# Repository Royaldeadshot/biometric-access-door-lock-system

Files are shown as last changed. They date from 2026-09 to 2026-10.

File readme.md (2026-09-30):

# ESP32 Based Biometric Access Door Lock (Tailored for GYM)

## Motivation
I used to go my GYM and used to see this biometric access door lock, and one day it struck me, I can make one too, with some extra features. So here i'm building this.

## Features
1. **Fingerprint** Based Recognition.
2. **Exit** by Pressing a Button inside.
3. **Cool LED ring** around the Fingerprint sensor for Visual Feedback, which also shows cool animations while idle.
4. **Buzzer** for Audible Feedback.
5. **Real Time member** list fetching from Website's Database. (No extra hardware like a laptop required for its working, just a wifi connection and it works like a charm.)
6. **Easy Integration** with any custom website.
7. A Fail Secure Solenoid Door Lock, it keeps locked when electricity is gone.

## Parts List

| Name | Qty | Link | $ Price |
| --- | --- | --- | --- |
| ESP32 | 1 | https://robocraze.com/products/esp32-development-board?_pos=1&_psq=esp&_psid=ffe363e30&_ss=e | 4.17 |
| R307S Fingerprint Scanner Module | 1 | https://robu.in/product/r307-optical-fingerprint-reader-module-sensor/ | 9.52 |
| Solenoid Door Lock | 1 | https://robocraze.com/products/12v-dc-lock-electric-solenoid-assembly?_pos=1&_sid=4b8eba6e6&_ss=r | 3.85 |
| 12V Power supply | 1 | https://robocraze.com/products/12-volt-2-amp-power-adapter-ac-to-dc?_pos=1&_psq=12v&_psid=6336dae56&_ss=e | 1.88 |
| 12V Relay | 1 | https://robocraze.com/products/12v-2-channel-relay-module-with-optocoupler-isolation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 | 0.93 |
| 12V to 5V Buck converter | 1 | https://robocraze.com/products/lm2596-dc-dc-buck-module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 | 0.5 |
| Buzzer | 1 | https://robocraze.com/products/3-volts-buzzer-small?_pos=1&_sid=47bbfcefe&_ss=r | 0.15 |
| Diode | 1 | https://robocraze.com/products/1n4007-diode-pack-of-10?_pos=1&_sid=7c56ba663&_ss=r | 0.16 |
| Switch | 1 | any kind of push switch works | 0 |
| LED (sk6812 mini e) | 8 | I just have them, i don't have a link of those | 0 |
| 3d Printed Enclosure | 1 | Source by Hackclub Printing  Legion | 5 |
| Diffuser sheet | 1 | find something which can diffuse light well enough | 0 |
| Jumper wires | - | https://robocraze.com/products/jumper-wire-set-m2m-m2f-f2f-40-pcs-each | 1.45 |
| M3 Heatset inserts | 4 | - | 0 |
| M3 Screws | 4 | - | 0 |
| | | TOTAL | 27.61 |
## Images
### Wiring
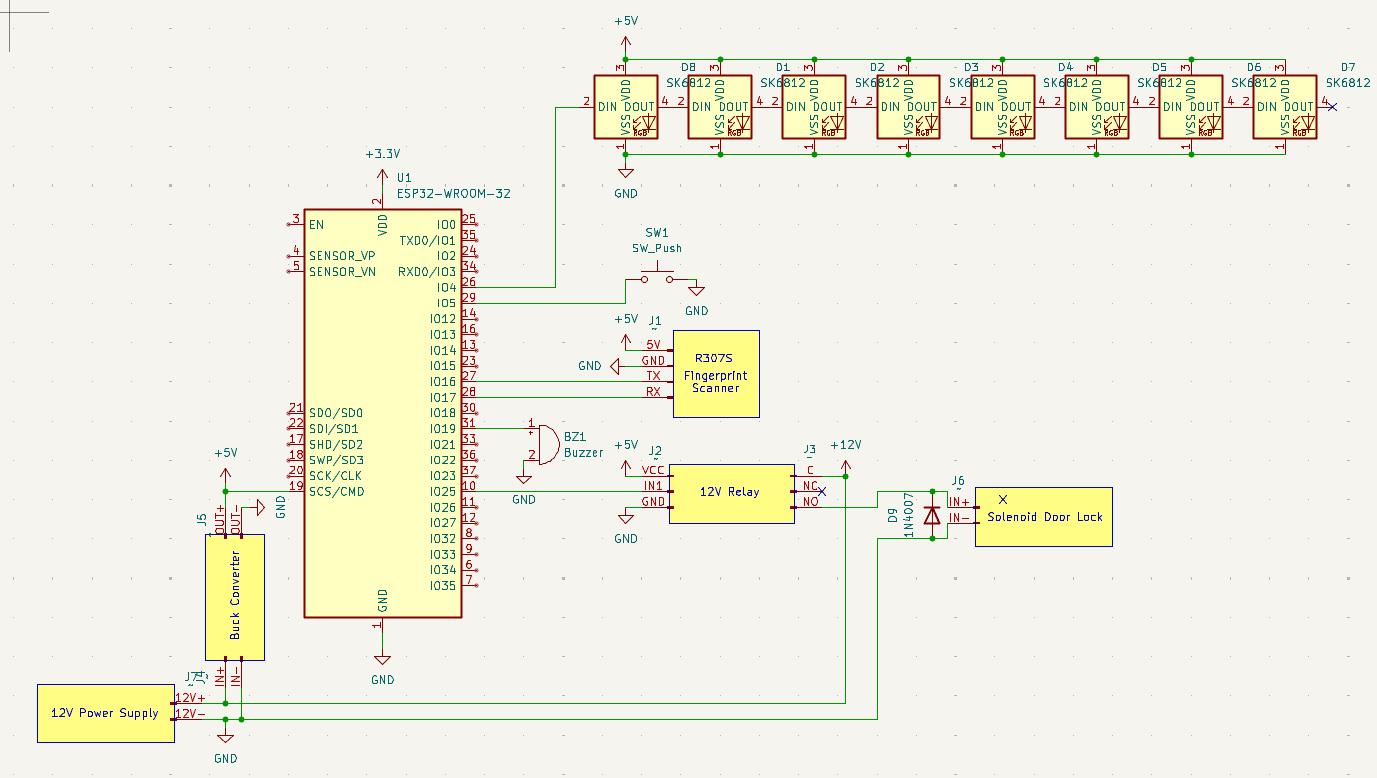
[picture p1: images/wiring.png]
wiring image


### 3D Model
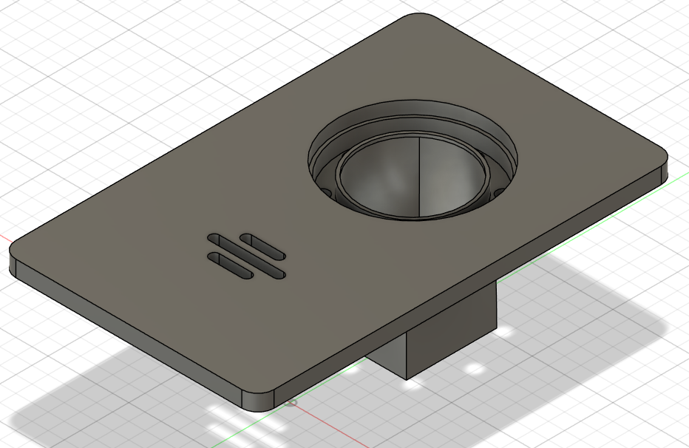
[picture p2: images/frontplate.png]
Frontplate

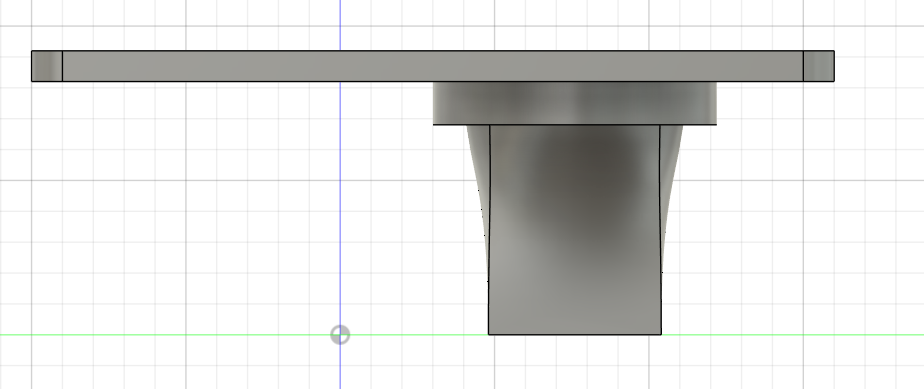
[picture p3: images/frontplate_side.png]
frontplate t

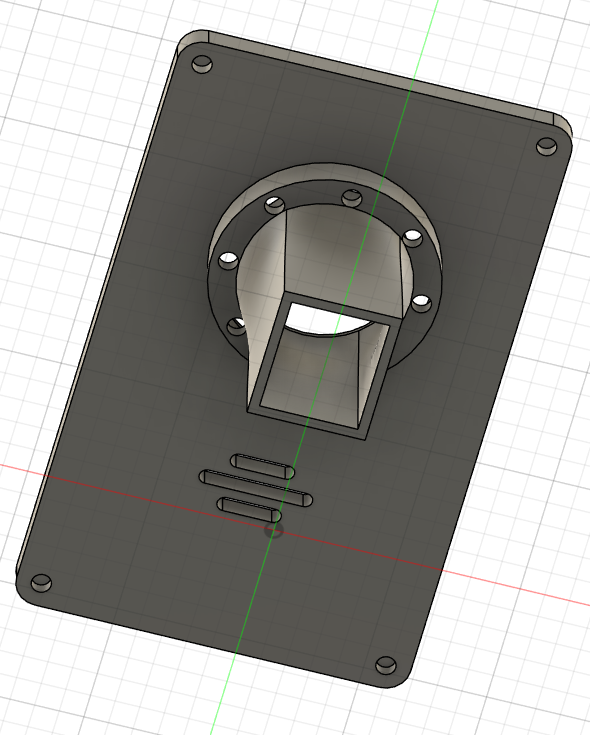
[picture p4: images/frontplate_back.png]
frontplate b

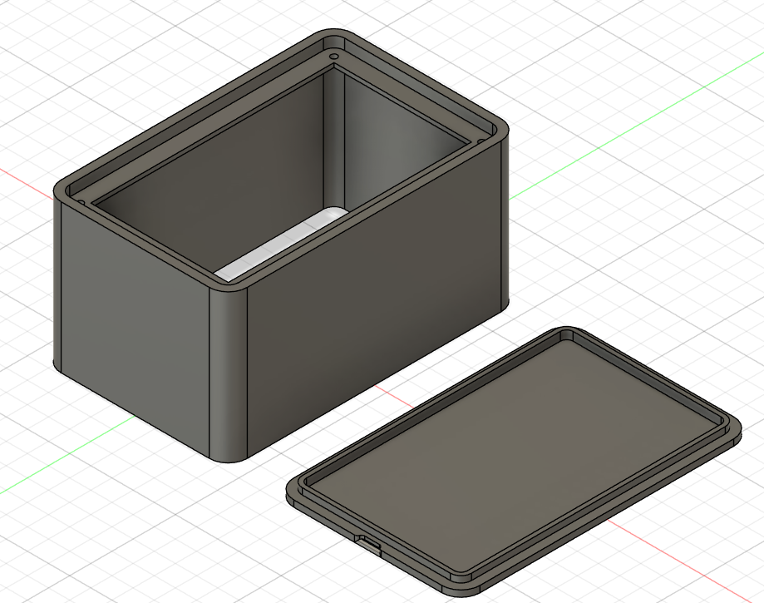
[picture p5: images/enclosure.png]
enclosure

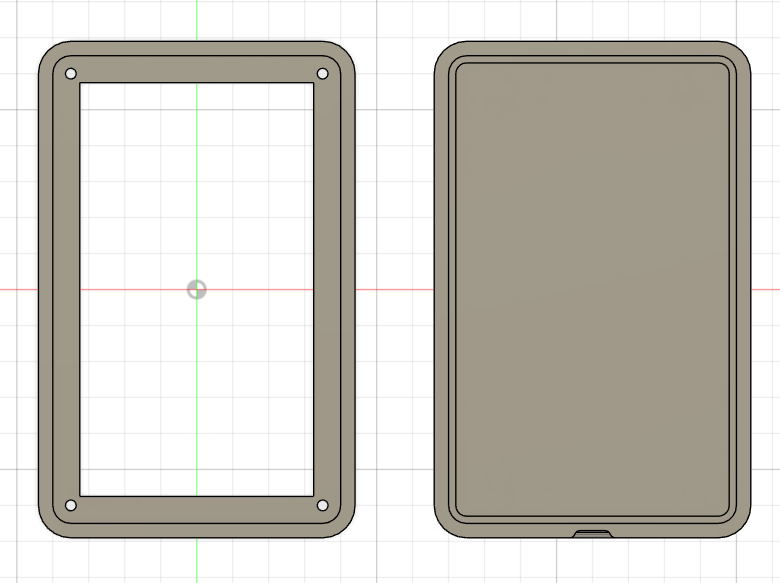
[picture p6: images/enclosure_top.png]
enclosure t

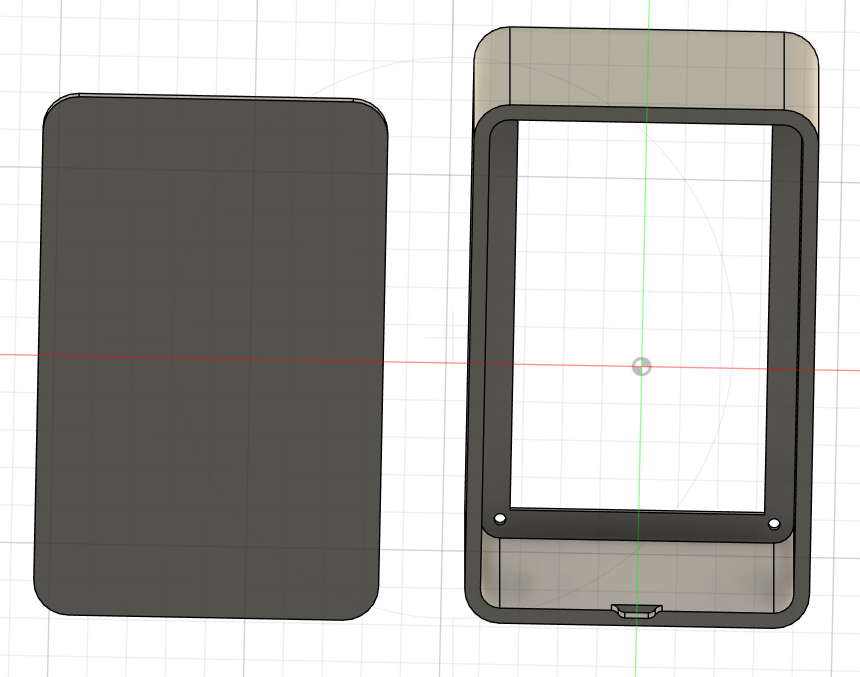
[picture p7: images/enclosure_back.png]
enclosure b


## FInished Build Image
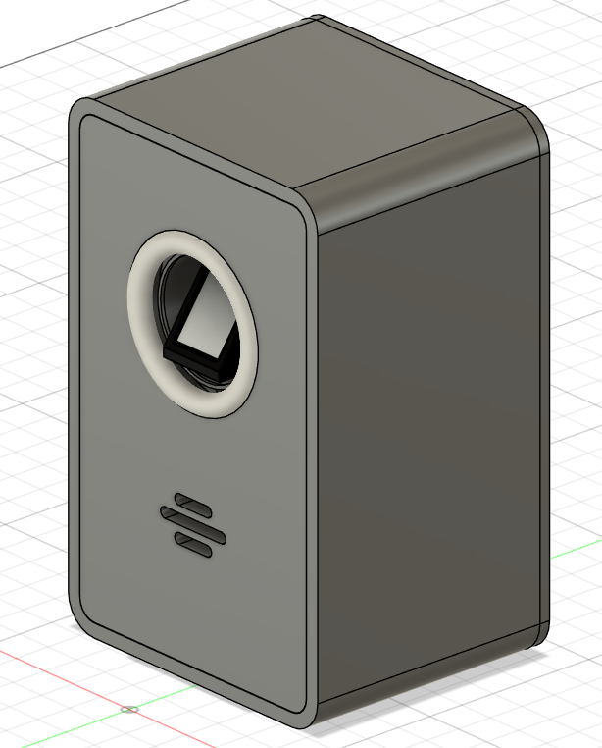
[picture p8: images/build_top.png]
build top

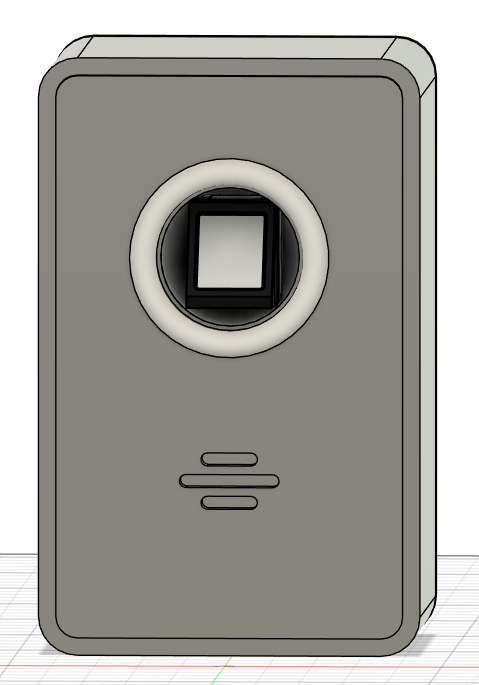
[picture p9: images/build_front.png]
build front

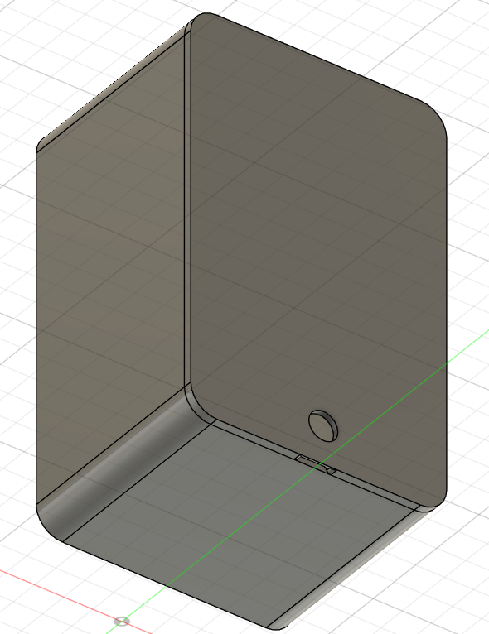
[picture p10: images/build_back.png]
build back


## Code
Code avaialble In the Code folder of this repository. Flash the code using arduino ide, and also install theese libraries Adafruit Fingerprint, FastLED, Firebase ESP32 Client.

## Working Flow

### 1. Access Attempt → Member Scans Finger
1. Member places finger on the R307S fingerprint scanner.
2. The R307S captures the scan and checks it against the fingerprint templates stored on the sensor itself, retrieving a matched fingerprint ID if one exists.
3. The ESP32 takes that fingerprint ID and queries the gym management website's database to check whether a member record is linked to it.

Case A — Member found, membership active

LED ring blinks green
* Buzzer beeps once
* Relay activates, retracting the solenoid lock for 2-3 seconds (exact duration to be finalized after physical testing)
* Door opens, lock releases automatically once the retract window ends

Case B — Member found, membership expired

* LED ring blinks red
* Buzzer beeps rapidly, 3 times
* Lock stays engaged, door does not open

Case C — Fingerprint not recognized (no matching record)

* LED ring turns orange
* Buzzer stays silent
* Lock stays engaged door does not open

### 2. Exit → Push Button
* Member presses the exit button on the inside of the door.
* No fingerprint check is required, this triggers the relay directly, retracting the lock and opening the door.
* This ensures free exit at all times, independent of the membership check or fingerprint recognition.

### 3. New Member Enrollment
1. Gym owner clicks "Register" on the gym management website and fills in the new member's details.
2. The website sends an enrollment request to the ESP32.
3. The ESP32 switches the R307S sensor into enrollment mode.
4. During this process, the LED ring displays a circular loading animation in yellow, giving visual feedback that enrollment is in progress.
5. The new member places their finger on the scanner, the sensor captures and stores the fingerprint template internally, generating a new fingerprint ID.
6. Once the scan completes successfully, the LED animation turn purple for 5 seconds and then goes to idle, (signaling completion).
7. The ESP32 sends the newly generated fingerprint ID back to the website, which stores it against that member's record in the database completing the link between "fingerprint" and "member."

## Website
* The website is hosted and accesible on this url- https://fitnessbox.vercel.app
* Here is the website's Repo link- https://github.com/Royaldeadshot/gym-management
* Just Copy the repo and host it and connect firebase and add email/password auth to acces the site.
* Currently the website is not integrated yet, once i get the parts all joined up then I will connect the two, the website and the biometric door lock system.

## Assembly Instruction
Insert the Fingerprint Sensor into the front plate from the front by sliding it in, and apply hot glue gun to fix it there, and using soldering iron, insert the heatset insert into the front plate and then place the led on a circular cardboard and place them there with superglue aand wire them up and then place them from the behind matching with holes provided in the circular ring. now keep the front and back open of the enclosure and place the esp32 and the relay and buck converter, hot glue them to fix them in place, and do the wiring as mentioned in the wiring diagram, and then close the frontplate and screw it in now run the 12v power wires, exit switch wire, solenoid door lock wires, from the hole at the back and wire them up with their respective part. for diffusion, i will place a tanslucent acrylic or plastic sheet by cutting it in circular shape and insert it in, and fill the groove with hot glue gun using the white glue stick which is nearly opaque. And then connect the esp32 with pc to flash the code, and then close up the back panel, it will just fir in right there by pushing it in.

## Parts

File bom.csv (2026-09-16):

S. No. | Part Name | Price | Quantity | Total Amount | Link
1 | ESP32 | 4.17 | 1 | 4.17 | https://robocraze.com/products/esp32-development-board?_pos=1&_psq=esp&_psid=ffe363e30&_ss=e
2 | Fingerprint Scanner Module | 9.52 | 1 | 9.52 | https://robu.in/product/r307-optical-fingerprint-reader-module-sensor/
3 | jumper wire set | 1.45 | 1 | 1.45 | https://robocraze.com/products/jumper-wire-set-m2m-m2f-f2f-40-pcs-each
4 | Solenoid Door Lock | 3.85 | 1 | 3.85 | https://robocraze.com/products/12v-dc-lock-electric-solenoid-assembly?_pos=1&_sid=4b8eba6e6&_ss=r
5 | 12V Power supply | 1.88 | 1 | 1.88 | https://robocraze.com/products/12-volt-2-amp-power-adapter-ac-to-dc?_pos=1&_psq=12v&_psid=6336dae56&_ss=e
6 | 12V Relay | 0.93 | 1 | 0.93 | https://robocraze.com/products/12v-2-channel-relay-module-with-optocoupler-isolation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
7 | 12V to 5V Buck converter | 0.5 | 1 | 0.5 | https://robocraze.com/products/lm2596-dc-dc-buck-module?_pos=1&_psid=99fdbbb4d&_ss=e
8 | Buzzer | 0.15 | 1 | 0.15 | https://robocraze.com/products/3-volts-buzzer-small?_pos=1&_sid=47bbfcefe&_ss=r
9 | Diode | 0.16 | 1 | 0.16 | https://robocraze.com/products/1n4007-diode-pack-of-10?_pos=1&_sid=7c56ba663&_ss=r
10 | Switch | 0 | 1 | 0 | Sourced by me
11 | LED | 0 | 8 | 0 | sourced by me
12 | 3D printed case | 5 | 1 | 5 | sourced by Printing legion
13 | M3 Screws and heatset | 0 | 4 | 0 | sourced by me
14 | Diffuser sheet | 0 | 1 | 0 | sourced by me
 |  |  | Total | 27.61

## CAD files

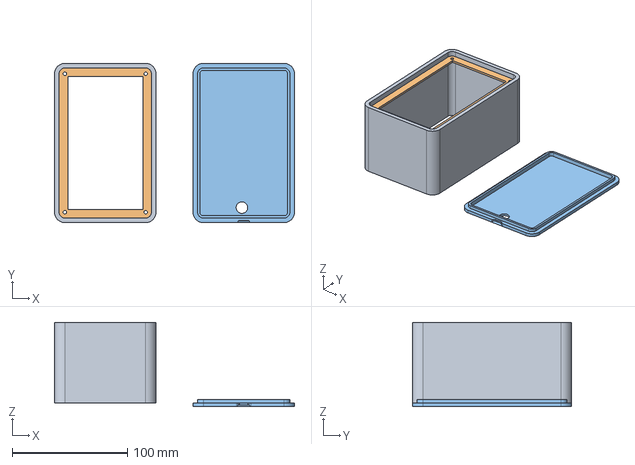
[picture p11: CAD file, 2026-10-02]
CAD/step/biometric scanner enclosure.step
208.0 x 138.0 x 73.0 mm

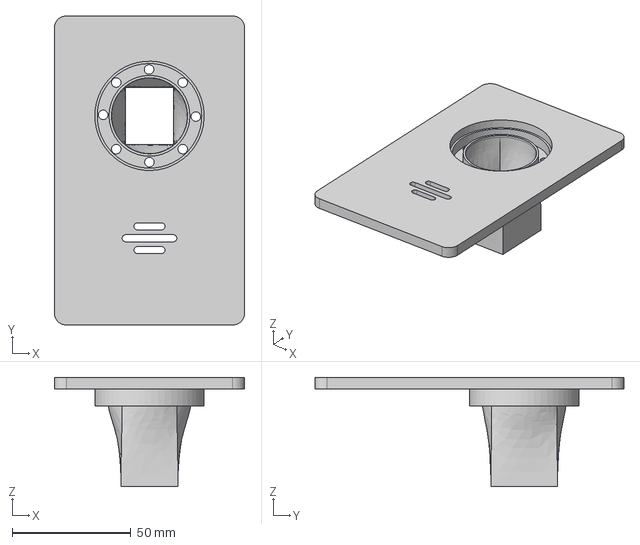
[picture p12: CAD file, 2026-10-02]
CAD/step/biometric scanner front plate.step
80.0 x 130.0 x 46.0 mm

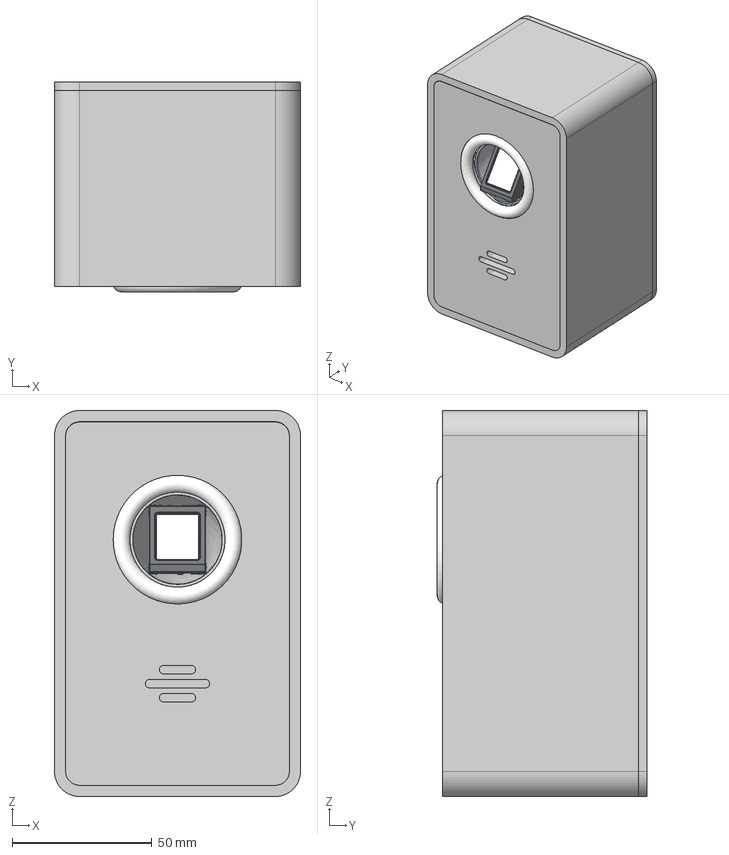
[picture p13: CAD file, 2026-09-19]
CAD/step/Finished build.step
88.0 x 75.0 x 138.0 mm

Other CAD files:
CAD/f3d/Finished build.f3z
CAD/f3d/biometric scanner enclosure.f3d
CAD/f3d/biometric scanner front plate.f3d

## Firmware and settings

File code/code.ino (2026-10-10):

#include <WiFi.h>
#include <WiFiClientSecure.h>
#include <HTTPClient.h>
#include <WebServer.h>
#include <DNSServer.h>
#include <Preferences.h>
#include <Adafruit_Fingerprint.h>
#include <time.h>
#include "secrets.h"
#include <driver/gpio.h>
#include <Update.h>
#include <esp_ota_ops.h>
#include <esp_partition.h>

// ==========================================
// 1. PIN DEFINITIONS & CONSTANTS
// ==========================================
#define FIRMWARE_VERSION "v1.2.0"

// Fingerprint Sensor (R307S)
#define RX_PIN 16         // ESP32 RX2 <- R307S TX (Yellow Wire)
#define TX_PIN 17         // ESP32 TX2 -> R307S RX (Green Wire)
#define TOUCH_PIN 4       // ESP32 GPIO4 <- R307S Touch Out (Blue Wire)
                          // (White Wire connects to ESP32 3.3V)

// Audio Feedback (Active Buzzer)
#define BUZZER_PIN 19     // Active Buzzer Positive (+) -> GPIO 19. Negative (-) -> GND

// Door Lock Relay (Solenoid)
#define RELAY_PIN 25      // ESP32 GPIO 25 (Pin D25) -> Relay IN pin
#define RELAY_ACTIVE_LEVEL LOW
#define RELAY_INACTIVE_LEVEL HIGH

// Interior Push-to-Exit Button
#define EXIT_BUTTON_PIN 27       // ESP32 GPIO 27 (Pin D27) -> Switch Pin 1. Switch Pin 2 -> GND

// LED Ring (Future)
#define LED_PIN 18               // WS2812 / SK6812 LED Ring Data (GPIO 18)

// Sensor limits
const uint8_t MAX_SENSOR_CAPACITY = 127;

// Captive Portal AP Configuration
const char* AP_SSID = "FitnessBox-Scanner";

// ==========================================
// OBJECTS & GLOBALS
// ==========================================
Adafruit_Fingerprint finger = Adafruit_Fingerprint(&Serial2);
Preferences prefs;
WebServer server(80);
DNSServer dnsServer;

bool isSetupMode = false;
unsigned long setupModeStartedAt = 0;
const unsigned long SETUP_PORTAL_TIMEOUT_MS = 600000; // 10 minutes auto-restart recovery

String storedSSID = "";
String storedPassword = "";
String storedLinkingKey = "";
String linkedGymId = "";

unsigned long lastCommandCheck = 0;
const unsigned long COMMAND_CHECK_INTERVAL = 3000; // Polling commands & sync signal

unsigned long lastOtaCheck = 0;
const unsigned long OTA_CHECK_INTERVAL = 1800000; // 30 minutes infrequent OTA check

// Non-blocking Solenoid State
bool isSolenoidUnlocked = false;
unsigned long solenoidRelockAt = 0;

// Firebase Auth Token Caching
String cachedIdToken = "";
unsigned long tokenExpiresAt = 0;

// ==========================================
// LOCAL MEMBER CACHE SYSTEM (<15ms OFFLINE ACCESS)
// ==========================================
struct MemberCacheEntry {
  bool valid;
  bool active;
  char expiryDate[11]; // YYYY-MM-DD
  char name[32];
};
MemberCacheEntry localCache[MAX_SENSOR_CAPACITY + 1];

// Forward declarations
void soundAccessGranted();
void soundAccessDeniedUnknown();
void soundAccessDeniedExpired();
void soundExitButton();
void soundSystemBoot();
void soundCloudOnline();
void soundEnrollPrompt();
void soundEnrollStep1();
void soundEnrollSuccess();
void soundEnrollFailed();
void soundConfigMode();
void triggerSolenoid(int durationSeconds);
void updateSolenoidState();
String extractJsonField(const String &json, const String &fieldName);
String getTodayDateString();
void logAccessEvent(String type, String memberId, String reason);
void applyAuthHeader(HTTPClient &https);

// ==========================================
// 2. AESTHETIC ACTIVE BUZZER AUDIO SUITE
// ==========================================
void activeBeep(int durationMs, int pauseMs = 35) {
  digitalWrite(BUZZER_PIN, HIGH);
  delay(durationMs);
  digitalWrite(BUZZER_PIN, LOW);
  if (pauseMs > 0) delay(pauseMs);
}

void soundAccessGranted() {
  activeBeep(28, 25);
  activeBeep(42, 30);
  activeBeep(140, 0);
}

void soundAccessDeniedUnknown() {
  activeBeep(22, 55);
  activeBeep(22, 0);
}

void soundAccessDeniedExpired() {
  activeBeep(70, 50);
  activeBeep(70, 110);
  activeBeep(200, 0);
}

void soundExitButton() {
  activeBeep(32, 0);
}

void soundSystemBoot() {
  Serial.println("🔊 [SYSTEM BOOT] Power-on sequence...");
  activeBeep(25, 30);
  activeBeep(35, 30);
  activeBeep(50, 40);
  activeBeep(160, 0);
}

void soundCloudOnline() {
  Serial.println("🔊 [CLOUD ONLINE] Connected & armed!");
  delay(80);
  activeBeep(38, 45);
  activeBeep(200, 0);
}

void soundEnrollPrompt() {
  activeBeep(40, 40);
  activeBeep(40, 40);
  activeBeep(85, 0);
}

void soundEnrollStep1() {
  activeBeep(55, 0);
}

void soundEnrollSuccess() {
  activeBeep(30, 25);
  activeBeep(30, 25);
  activeBeep(30, 55);
  activeBeep(65, 35);
  activeBeep(260, 0);
}

void soundEnrollFailed() {
  for (int i = 0; i < 4; i++) {
    activeBeep(45, 35);
  }
}

void soundConfigMode() {
  activeBeep(45, 45);
  activeBeep(45, 120);
  activeBeep(90, 0);
}

// ==========================================
// 3. HARDWARE CONTROL (NON-BLOCKING SOLENOID)
// ==========================================
void triggerSolenoid(int durationSeconds) {
  Serial.printf("⚡ [DOOR LOCK] Unlocking door for %d seconds...\n", durationSeconds);
  digitalWrite(RELAY_PIN, RELAY_ACTIVE_LEVEL);
  solenoidRelockAt = millis() + (unsigned long)(durationSeconds * 1000);
  isSolenoidUnlocked = true;
}

void updateSolenoidState() {
  if (isSolenoidUnlocked && millis() >= solenoidRelockAt) {
    digitalWrite(RELAY_PIN, RELAY_INACTIVE_LEVEL);
    isSolenoidUnlocked = false;
    Serial.println("🔒 [DOOR LOCK] Relocked.");
  }
}

void triggerLedAccessGranted()        { Serial.println("💡 [LED RING] Green pulse"); }
void triggerLedAccessDeniedExpired()  { Serial.println("💡 [LED RING] Rapid red pulse"); }
void triggerLedAccessDeniedUnknown()  { Serial.println("💡 [LED RING] Amber steady"); }
void triggerLedEnrollScanning()       { Serial.println("💡 [LED RING] Yellow rotating"); }
void triggerLedEnrollSuccess()        { Serial.println("💡 [LED RING] Purple completion"); }

// ==========================================
// 4. SECURE JSON & TIME HELPERS
// ==========================================
String extractJsonField(const String &json, const String &fieldName) {
  int fieldIdx = json.indexOf("\"" + fieldName + "\"");
  if (fieldIdx == -1) return "";

  int colonIdx = json.indexOf(":", fieldIdx);
  if (colonIdx == -1) return "";

  int stringValIdx = json.indexOf("\"stringValue\"", colonIdx);
  if (stringValIdx != -1 && stringValIdx < colonIdx + 45) {
    int valColonIdx = json.indexOf(":", stringValIdx);
    if (valColonIdx != -1) {
      int firstQuote = json.indexOf("\"", valColonIdx);
      if (firstQuote != -1) {
        int endQuote = json.indexOf("\"", firstQuote + 1);
        if (endQuote != -1) {
          return json.substring(firstQuote + 1, endQuote);
        }
      }
    }
  }

  int firstQuote = json.indexOf("\"", colonIdx);
  if (firstQuote == -1) return "";

  int endQuote = json.indexOf("\"", firstQuote + 1);
  if (endQuote == -1) return "";

  return json.substring(firstQuote + 1, endQuote);
}

String getTodayDateString() {
  struct tm timeinfo;
  if (!getLocalTime(&timeinfo, 1000)) {
    return "";
  }
  char buffer[12];
  strftime(buffer, sizeof(buffer), "%Y-%m-%d", &timeinfo);
  return String(buffer);
}

// ==========================================
// 5. LOCAL CACHE MANAGEMENT (PERSISTENT & FAST)
// ==========================================
void loadLocalCacheFromFlash() {
  prefs.begin("fb_cache", true);
  for (uint8_t i = 1; i <= MAX_SENSOR_CAPACITY; i++) {
    String key = "s_" + String(i);
    String val = prefs.getString(key.c_str(), "");
    if (val.length() > 0) {
      int p1 = val.indexOf('|');
      int p2 = val.indexOf('|', p1 + 1);
      if (p1 != -1 && p2 != -1) {
        localCache[i].valid = true;
        localCache[i].active = (val.substring(0, p1) == "ACTIVE");
        strncpy(localCache[i].expiryDate, val.substring(p1 + 1, p2).c_str(), 10);
        localCache[i].expiryDate[10] = '\0';
        strncpy(localCache[i].name, val.substring(p2 + 1).c_str(), 31);
        localCache[i].name[31] = '\0';
      }
    } else {
      localCache[i].valid = false;
    }
  }
  prefs.end();
  Serial.println("💾 [CACHE] Member cache loaded from NVS flash memory.");
}

void saveMemberToLocalCache(uint8_t slotId, bool active, const String &expiryDate, const String &name) {
  if (slotId < 1 || slotId > MAX_SENSOR_CAPACITY) return;

  localCache[slotId].valid = true;
  localCache[slotId].active = active;
  strncpy(localCache[slotId].expiryDate, expiryDate.c_str(), 10);
  localCache[slotId].expiryDate[10] = '\0';
  strncpy(localCache[slotId].name, name.c_str(), 31);
  localCache[slotId].name[31] = '\0';

  prefs.begin("fb_cache", false);
  String key = "s_" + String(slotId);
  String val = (active ? "ACTIVE|" : "EXPIRED|") + expiryDate + "|" + name;
  prefs.putString(key.c_str(), val);
  prefs.end();
}

// Full collection sync: EXECUTED ONLY ONCE AT FRESH BOOT
void syncActiveMembersCache() {
  if (WiFi.status() != WL_CONNECTED || linkedGymId == "") return;

  Serial.println("\n🔄 [CACHE] Performing initial sync of active members from Firestore...");
  WiFiClientSecure client;
  client.setInsecure();
  HTTPClient https;

  String url = "https://firestore.googleapis.com/v1/projects/" + String(FIREBASE_PROJECT_ID) + "/databases/(default)/documents/gyms/" + linkedGymId + ":runQuery";
  if (!https.begin(client, url)) return;

  applyAuthHeader(https);
  String queryPayload = "{\"structuredQuery\":{\"from\":[{\"collectionId\":\"members\"}],\"limit\":150}}";

  int httpCode = https.POST(queryPayload);
  if (httpCode == 200) {
    String resp = https.getString();
    int searchIdx = 0;
    int syncedCount = 0;

    while (true) {
      int docIdx = resp.indexOf("\"document\":", searchIdx);
      if (docIdx == -1) break;

      int nextDocIdx = resp.indexOf("\"document\":", docIdx + 11);
      String docChunk = (nextDocIdx != -1) ? resp.substring(docIdx, nextDocIdx) : resp.substring(docIdx);
      searchIdx = (nextDocIdx != -1) ? nextDocIdx : resp.length();

      String fingerIdStr = extractJsonField(docChunk, "fingerprint_id");
      String statusStr   = extractJsonField(docChunk, "status");
      String expiryStr   = extractJsonField(docChunk, "expiry_date");
      String nameStr     = extractJsonField(docChunk, "name");

      if (fingerIdStr.length() > 0) {
        int slot = fingerIdStr.toInt();
        if (slot >= 1 && slot <= MAX_SENSOR_CAPACITY) {
          bool isActive = (statusStr == "active");
          saveMemberToLocalCache((uint8_t)slot, isActive, expiryStr, nameStr);
          syncedCount++;
        }
      }
    }
    Serial.printf("✅ [CACHE] Initial boot sync complete (%d member records cached).\n", syncedCount);
  }
  https.end();
}

// Event-driven cache invalidation: ONLY syncs if website actually modified records!
void checkMemberCacheSyncSignal() {
  if (WiFi.status() != WL_CONNECTED || linkedGymId == "") return;

  WiFiClientSecure client;
  client.setInsecure();
  HTTPClient https;

  String url = "https://firestore.googleapis.com/v1/projects/" + String(FIREBASE_PROJECT_ID) + "/databases/(default)/documents/gyms/" + linkedGymId + "/scanners/sync";
  if (!https.begin(client, url)) return;

  applyAuthHeader(https);
  int httpCode = https.GET();
  if (httpCode == 200) {
    String resp = https.getString();
    String syncNeeded = extractJsonField(resp, "sync_needed");

    if (syncNeeded == "true" || syncNeeded == "TRUE") {
      Serial.println("\n🔔 [EVENT-DRIVEN SYNC] Detected member changes from web dashboard!");
      String slotStr = extractJsonField(resp, "slot_id");

      if (slotStr.length() > 0 && slotStr != "ALL") {
        // ULTRA-EFFICIENT SINGLE-SLOT UPDATE: Zero member collection reads!
        int slot = slotStr.toInt();
        String status = extractJsonField(resp, "status");
        String expiry = extractJsonField(resp, "expiry_date");
        String name   = extractJsonField(resp, "name");

        if (status == "deleted") {
          localCache[slot].valid = false;
          prefs.begin("fb_cache", false);
          prefs.remove(("s_" + String(slot)).c_str());
          prefs.end();
          Serial.printf("🗑️ [CACHE] Removed Slot #%d from local cache.\n", slot);
        } else {
          saveMemberToLocalCache((uint8_t)slot, (status == "active"), expiry, name);
          Serial.printf("⚡ [CACHE] Targeted single-slot update: Slot #%d (%s, %s)\n", slot, name.c_str(), status.c_str());
        }
      } else {
        // Bulk sync only when explicitly requested
        syncActiveMembersCache();
      }

      // Reset flag to false so no further reads occur until next user action
      https.end();
      String patchUrl = url + "?updateMask.fieldPaths=sync_needed";
      if (https.begin(client, patchUrl)) {
        applyAuthHeader(https);
        String patchPayload = "{\"fields\":{\"sync_needed\":{\"stringValue\":\"false\"}}}";
        https.PATCH(patchPayload);
      }
    }
  }
  https.end();
}

// ==========================================
// 6. FIREBASE AUTH & REST API CALLS
// ==========================================
String getFirebaseAuthToken() {
  #ifdef FIREBASE_AUTH_EMAIL
    if (String(FIREBASE_AUTH_EMAIL).length() > 0 && String(FIREBASE_AUTH_PASSWORD).length() > 0) {
      if (cachedIdToken.length() > 0 && millis() < tokenExpiresAt) {
        return cachedIdToken;
      }
      
      if (WiFi.status() != WL_CONNECTED) return "";
      
      WiFiClientSecure client;
      client.setInsecure();
      HTTPClient https;
      
      String authUrl = "https://identitytoolkit.googleapis.com/v1/accounts:signInWithPassword?key=" + String(FIREBASE_API_KEY);
      if (https.begin(client, authUrl)) {
        https.addHeader("Content-Type", "application/json");
        String payload = "{\"email\":\"" + String(FIREBASE_AUTH_EMAIL) + "\",\"password\":\"" + String(FIREBASE_AUTH_PASSWORD) + "\",\"returnSecureToken\":true}";
        int httpCode = https.POST(payload);
        if (httpCode == 200) {
          String resp = https.getString();
          String token = extractJsonField(resp, "idToken");
          if (token.length() > 0) {
            cachedIdToken = token;
            tokenExpiresAt = millis() + (3000UL * 1000UL); // 50 min
            https.end();
            return cachedIdToken;
          }
        }
        https.end();
      }
    }
  #endif
  return "";
}

void applyAuthHeader(HTTPClient &https) {
  https.addHeader("Content-Type", "application/json");
  String token = getFirebaseAuthToken();
  if (token.length() > 0) {
    https.addHeader("Authorization", "Bearer " + token);
  }
}

String resolveGymIdFromLinkingKey(String key) {
  if (WiFi.status() != WL_CONNECTED) return "";
  
  WiFiClientSecure client;
  client.setInsecure();
  HTTPClient https;
  
  String url = "https://firestore.googleapis.com/v1/projects/" + String(FIREBASE_PROJECT_ID) + "/databases/(default)/documents/gym_links/" + key;
  if (https.begin(client, url)) {
    applyAuthHeader(https);
    int httpCode = https.GET();
    if (httpCode == 200) {
      String resp = https.getString();
      String foundGym = extractJsonField(resp, "gym_id");
      if (foundGym.length() > 0) {
        https.end();
        return foundGym;
      }
    }
    https.end();
  }
  return "";
}

// Log event to Firestore (with offline fallback)
void logAccessEvent(String type, String memberId, String reason) {
  if (WiFi.status() != WL_CONNECTED || linkedGymId == "") {
    Serial.println("📝 [LOG] Wi-Fi offline. Buffered event locally.");
    return;
  }
  
  WiFiClientSecure client;
  client.setInsecure();
  HTTPClient https;
  
  String url = "https://firestore.googleapis.com/v1/projects/" + String(FIREBASE_PROJECT_ID) + "/databases/(default)/documents/gyms/" + linkedGymId + "/logs";
  if (!https.begin(client, url)) return;
  
  applyAuthHeader(https);
  String payload = "{\"fields\":{"
    "\"type\":{\"stringValue\":\"" + type + "\"},"
    "\"member_id\":{\"stringValue\":\"" + memberId + "\"},"
    "\"reason\":{\"stringValue\":\"" + reason + "\"},"
    "\"timestamp\":{\"stringValue\":\"" + String(millis()) + "\"}"
  "}}";
  
  https.POST(payload);
  https.end();
}

// Check for Remote Door Unlock commands from Dashboard
void checkRemoteUnlockCommand() {
  if (WiFi.status() != WL_CONNECTED || linkedGymId == "") return;

  WiFiClientSecure client;
  client.setInsecure();
  HTTPClient https;

  String url = "https://firestore.googleapis.com/v1/projects/" + String(FIREBASE_PROJECT_ID) + "/databases/(default)/documents/gyms/" + linkedGymId + "/scanners/commands";
  if (!https.begin(client, url)) return;

  applyAuthHeader(https);
  int httpCode = https.GET();
  if (httpCode == 200) {
    String resp = https.getString();
    String cmd = extractJsonField(resp, "command");
    String st  = extractJsonField(resp, "status");
    if (cmd == "UNLOCK" && st == "PENDING") {
      Serial.println("\n⚡ [REMOTE UNLOCK] Command received from Web Dashboard!");
      soundAccessGranted();
      triggerSolenoid(3);
      logAccessEvent("REMOTE_UNLOCK", "ADMIN", "Dashboard Remote Open");

      // Mark command COMPLETED
      https.end();
      String patchUrl = url + "?updateMask.fieldPaths=status";
      if (https.begin(client, patchUrl)) {
        applyAuthHeader(https);
        String patchPayload = "{\"fields\":{\"status\":{\"stringValue\":\"COMPLETED\"}}}";
        https.PATCH(patchPayload);
      }
    }
  }
  https.end();
}

// Check website for enrollment commands
void checkEnrollmentRequest() {
  if (WiFi.status() != WL_CONNECTED || linkedGymId == "") return;
  
  WiFiClientSecure client;
  client.setInsecure();
  HTTPClient https;
  
  String url = "https://firestore.googleapis.com/v1/projects/" + String(FIREBASE_PROJECT_ID) + "/databases/(default)/documents/gyms/" + linkedGymId + "/scanners/enrollment";
  if (!https.begin(client, url)) return;
  
  applyAuthHeader(https);
  int httpCode = https.GET();
  if (httpCode == 200) {
    String resp = https.getString();
    String cmd = extractJsonField(resp, "command");
    String st  = extractJsonField(resp, "status");
    if (cmd == "ENROLL" && st == "PENDING") {
      Serial.println("\n🌐 ENROLLMENT COMMAND RECEIVED FROM WEBSITE!");
      runEnrollmentProcess();
    }
  }
  https.end();
}

void updateEnrollmentStatus(String status, uint8_t fingerId) {
  if (WiFi.status() != WL_CONNECTED || linkedGymId == "") return;
  
  WiFiClientSecure client;
  client.setInsecure();
  HTTPClient https;
  
  String url = "https://firestore.googleapis.com/v1/projects/" + String(FIREBASE_PROJECT_ID) + "/databases/(default)/documents/gyms/" + linkedGymId + "/scanners/enrollment?updateMask.fieldPaths=status&updateMask.fieldPaths=fingerprint_id";
  if (!https.begin(client, url)) return;
  
  applyAuthHeader(https);
  String payload = "{\"fields\":{"
    "\"status\":{\"stringValue\":\"" + status + "\"},"
    "\"fingerprint_id\":{\"stringValue\":\"" + String(fingerId) + "\"}"
  "}}";
  
  https.PATCH(payload);
  https.end();
}

// ==========================================
// 7. OVER-THE-AIR (OTA) ONLINE UPDATE & HARDWARE ROLLBACK
// ==========================================
void reportOtaStatus(String status, String version) {
  if (WiFi.status() != WL_CONNECTED || linkedGymId == "") return;

  WiFiClientSecure client;
  client.setInsecure();
  HTTPClient https;

  String url = "https://firestore.googleapis.com/v1/projects/" + String(FIREBASE_PROJECT_ID) + "/databases/(default)/documents/gyms/" + linkedGymId + "/scanners/ota?updateMask.fieldPaths=status&updateMask.fieldPaths=active_version";
  if (https.begin(client, url)) {
    applyAuthHeader(https);
    String payload = "{\"fields\":{"
      "\"status\":{\"stringValue\":\"" + status + "\"},"
      "\"active_version\":{\"stringValue\":\"" + version + "\"}"
    "}}";
    https.PATCH(payload);
    https.end();
  }
}
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
void loop() {
  if (isSetupMode) {
    dnsServer.processNextRequest();
    server.handleClient();
    if (millis() - setupModeStartedAt > SETUP_PORTAL_TIMEOUT_MS) {
      ESP.restart();
    }
    return;
  }

  // Non-blocking solenoid relay timer
  updateSolenoidState();

  // 1. Interior Push-to-Exit Button (Debounced)
  static bool lastExitButton = HIGH;
  bool currentExitButton = digitalRead(EXIT_BUTTON_PIN);
  if (lastExitButton == HIGH && currentExitButton == LOW) {
    delay(20);
    if (digitalRead(EXIT_BUTTON_PIN) == LOW) {
      Serial.println("🚪 [EXIT] Interior Exit Button Pressed!");
      soundExitButton();
      triggerSolenoid(3);
      logAccessEvent("EXIT", "INTERIOR_BUTTON", "Free exit");
    }
  }
  lastExitButton = currentExitButton;

  // 2. Member Fingerprint Scan (Cache-first <15ms)
  if (digitalRead(TOUCH_PIN) == LOW) {
    handleFingerprintVerification();
  }

  // 3. Command & Sync Polling (Enrollment, Remote Unlock, and Event-Driven Sync Signal)
  if (millis() - lastCommandCheck > COMMAND_CHECK_INTERVAL) {
    lastCommandCheck = millis();
    checkEnrollmentRequest();
    checkRemoteUnlockCommand();
    checkMemberCacheSyncSignal(); // 💡 ONLY syncs when website actually modified records!
  }

  // 4. Infrequent OTA Check (Every 30 mins)
  if (millis() - lastOtaCheck > OTA_CHECK_INTERVAL) {
    lastOtaCheck = millis();
    checkOtaUpdate();
  }

  delay(20);
}

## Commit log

2026-09-04 shifted files
    [biometric access door lock.kicad_pcb, biometric access door lock.kicad_sch]
2026-09-04 wiring complete
    [biometric access door lock.kicad_sch, bom.xlsx]
2026-09-13 cad files and code
    [biometric scanner enclosure.f3d, biometric scanner enclosure.step, biometric scanner enclosure.stl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]
2026-09-19 finish build files
    [Finished build.f3z, Finished build.step]
